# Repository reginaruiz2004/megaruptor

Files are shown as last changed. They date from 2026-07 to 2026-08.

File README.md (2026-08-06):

# Megaruptor

An open-source, low-cost DNA shearing device built on the [Poseidon syringe pump](https://github.com/machineagency/poseidon) platform — designed as an accessible alternative to commercial mechanical shearing instruments (e.g., Diagenode Megaruptor 3) for genomic library preparation workflows, particularly long-read sequencing (Oxford Nanopore).

> **Status:** 🚧 In progress

---

## Overview

Mechanical DNA shearing instruments are a common bottleneck in labs working with long-read sequencing platforms, both in cost and accessibility. This project adapts the open-source Poseidon syringe pump design to build a functional, hackable shearing device using off-the-shelf electronics, 3D-printed parts, and standard insulin syringes as the shearing element.

The goal is a device that is:
- **Low-cost** — built from widely available components
- **Reproducible** — fully documented, open hardware
- **Hackable** — easy to modify shear force/speed parameters for different fragment size targets

---

## How It Works

DNA is sheared by repeatedly forcing a sample through a narrow-gauge needle at controlled speed, using a syringe pump mechanism driven by a stepper motor. Shear force and fragment size distribution are governed by needle gauge, plunger speed, and number of passes.

---

## Bill of Materials (Key Components)

| Component | Spec / Notes |
|---|---|
| Shearing element | BD Ultra-Fine 0.3 mL, 31G insulin syringes |
| Stepper motor | NEMA 17 |
| Motor driver | A4988 |
| Controller | CNC Shield V3 + Arduino Uno R3 |
| Safety | Mechanical limit switch (NC, fail-safe primary) + current sensing (secondary) |
| Frame/structural parts | 3D-printed (PLA), based on Poseidon design |

Full BOM with vendor links: [`docs/BOM.md`](docs/BOM.md) *(coming soon)*

---

## 3D Printed Parts

This build uses 4 standard components from the original Poseidon design, plus 2 custom parts designed for this build:

| Part | Type | Notes |
|---|---|---|
| Poseidon base/frame components (×4) | Standard | From original Poseidon design |
| Sleeve adapter | Custom | OD 8 mm, ID 6.1 mm, 30 mm length |
| Eppendorf bracket | Custom | 45° angle mount |

All STL files are available in [`/STL`](./STL). Source CAD files (where available) are in [`/CAD`](./CAD).

---

## Repository Structure

```
megaruptor/
├── README.md
├── STL/                  # Printable 3D files
├── CAD/                  # Source CAD files (Fusion 360 / FreeCAD)
├── firmware/             # Arduino control code
├── docs/
│   ├── BOM.md            # Full bill of materials with vendors/costs
│   ├── DECISIONS.md      # Design decisions & rationale
│   ├── ASSEMBLY.md       # Build/assembly instructions
│   └── images/           # Build photos
```

---

## Design Decisions

Key engineering choices and their rationale are documented in [`docs/DECISIONS.md`](docs/DECISIONS.md), including:
- Hybrid safety design (mechanical limit switch + current sensing) over software-only stall detection
- Choice of insulin syringe gauge for shearing element
- Custom part tolerances (e.g., sleeve adapter fit)

---

## Build Progress

- [x] Source components (NEMA 17, A4988, Arduino Uno R3, syringes)
- [x] Design custom parts (sleeve adapter, Eppendorf bracket)
- [x] 3D print all components
- [x] Full mechanical assembly
- [ ] Firmware integration and motor control testing
- [ ] Validation with real DNA samples (fragment size distribution vs. commercial shearing)

---

## Progress Log

### July 21 2026
Mechanical assembly in progress. Key steps completed this round:

- Drilled out the rod holes on the 3D-printed PLA parts to fit the guide rods — the as-printed tolerances were too tight, so holes were carefully widened with a drill bit until the rods slid through smoothly.
- Installed screws on all designated screw holes across the printed parts to secure the frame.
- Threaded the brass (gold) lead screw nut onto the central leadscrew and secured it inside the carriage's nut trap with M3 screws, so it stays anti-rotated — this is what converts the leadscrew's rotation into linear motion, pulling the carriage along the two guide rods instead of just spinning freely with the screw.
- Mounted the carriage onto the guide rods and confirmed it slides smoothly along the full travel range by turning the leadscrew by hand.

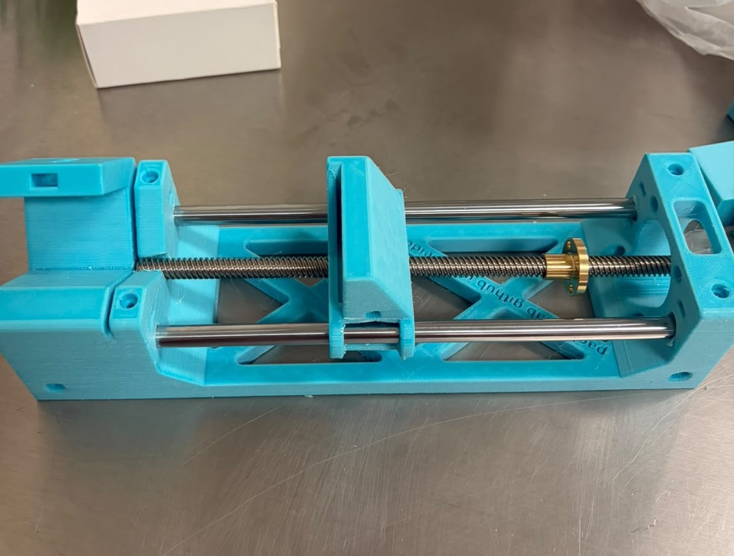
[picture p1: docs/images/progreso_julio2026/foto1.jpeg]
Progress Megaruptor


📹 [Watch the assembly video](docs/images/progreso_julio2026/video1.mp4)

### July 27, 2026

**A4988 Driver Calibration — Complete**

Key steps completed this round:

- Installed jumper headers at each motor position on the CNC shield to configure 1/2-step mode.
- Seated all four A4988 drivers into their respective positions on the CNC shield (X, Y, Z, and A axes).
- Mounted the CNC shield onto the Arduino UNO.
- Calibrated each A4988 driver to a reference voltage of 0.96V using a digital multimeter, with the negative probe on the CNC shield's GND pin and the positive probe used to measure the potentiometer during adjustment. This value was derived from: Vref = Imax × (8 × Rsense) = 1.2A × (8 × 0.1Ω) = 0.96V.
- Voltage adjustments were made by turning each driver's onboard potentiometer with a small screwdriver while simultaneously monitoring voltage with the multimeter's positive probe.
- Once all four drivers were calibrated to 0.96V, proceeded to connect the NEMA 17 stepper motor.
- **Note:** Many NEMA 17 motors ship with connectors where the wire color order differs between the motor and driver ends. This was the case here — the pin order did not match. To correct it, I released the terminals from the connector housing using a small screwdriver and reseated them in the correct sequence.
- Connected the NEMA 17 motor to the CNC shield via the X-axis A4988 driver.
- Stripped two jumper wires and connected them to the CNC shield's positive (+) and negative (–) power terminals to interface with the barrel jack adapter.

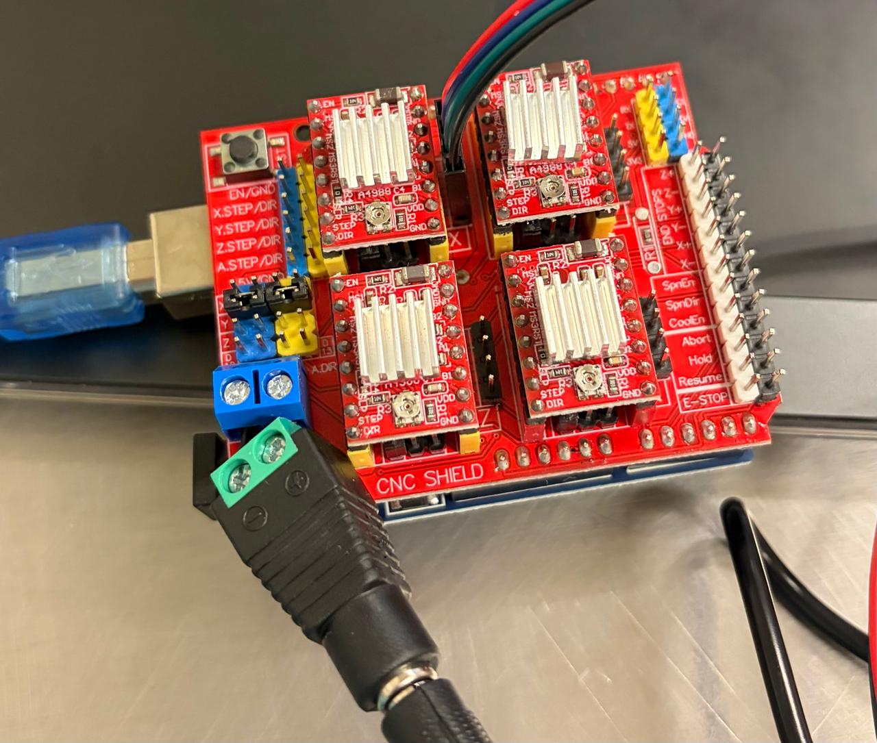
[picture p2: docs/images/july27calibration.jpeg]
Driver Calibration


### August 3, 2026

**NEMA 17 setup completed**

Key steps completed this round:

- Installed the NEMA17 into the megaruptor base support. Removed awkwardness when the NEMA17 motor turns on.
- Switched the main central screw to a smaller length one so it can all properly fit with now the NEMA17 closer to the whole device.
- I started having an issue with one of the rods whenever the cart moved forwards and backwards. The rod would also move with the cart's movements. To fix this, I setup longer screws in the base so that they would hold the rods in place without worry of any movement when the cart would begin to do its job.
- Completed a design of 3d printed case for the CNC shield and arduino. There are 5 openings in the case: Arduino USB cable, Jack Barrel power source for Arduino, On/Off switch, cart switch, and an opening for the NEMA 17 wires.

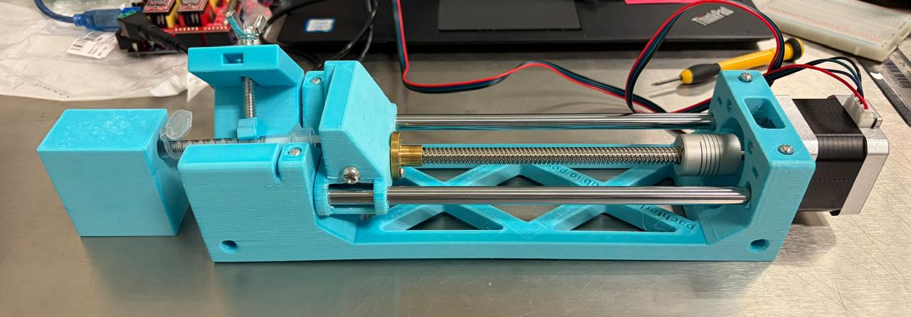
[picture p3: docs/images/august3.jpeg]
Setup


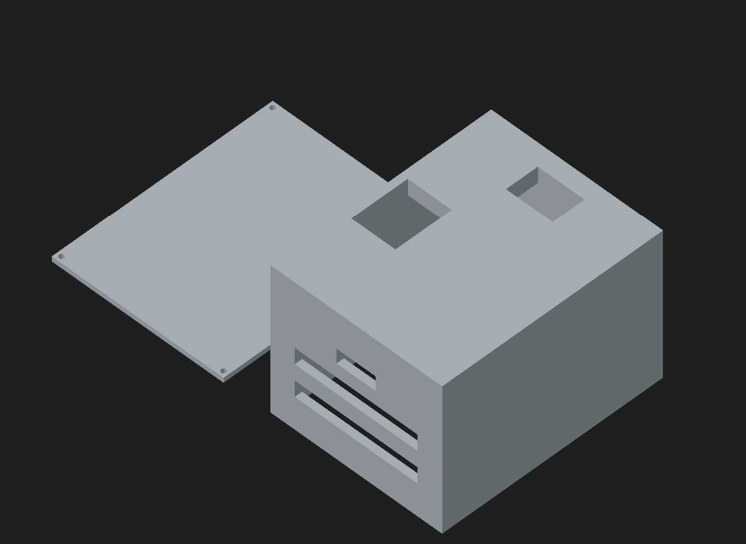
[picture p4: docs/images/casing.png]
Casing


### August 4, 2026

**3D Printed Case**

Key steps completed this round:

- I 3d printed the case for the electrical components.
- Switch assembly: On/Off switch, forwards/backwards switch that controls the cart movement

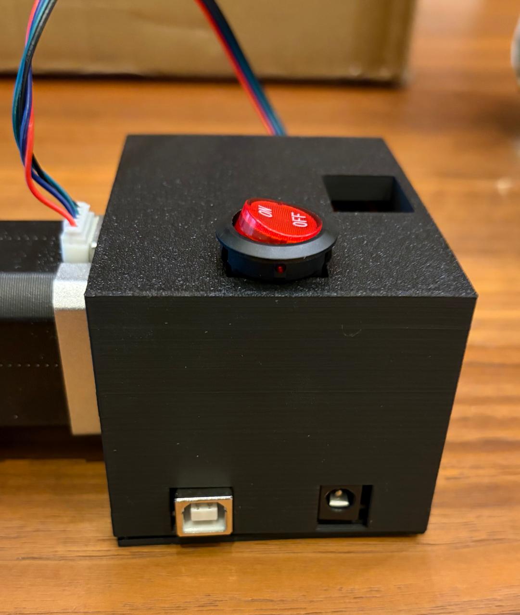
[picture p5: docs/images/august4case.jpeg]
Case

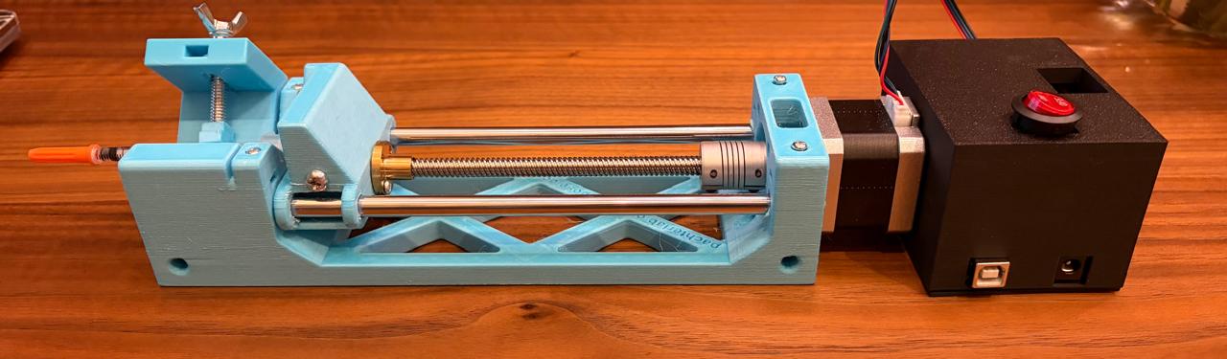
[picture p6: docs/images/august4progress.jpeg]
Complete machine


### August 5, 2026

**Complete setup of megaruptor**

Key steps completed this round:

- Connected the switch that moves the cart forwards and backwards. I connected it directly to the CNC shield instead of the Arduino. Why? Because all of the pins from the arduino are taken by the CNC shield since it is stacked. Therefore, there are pins in the CNC shield that are available to act as digital pins. (Y+ and Z- were used in this case)
- Connected the on and off switch with the following circuit. Terminal 1 (LED) was connected to the gnd of the CNC shield. There was also a wire from CNC shield GND soldered to the Arduino GND pin of the jack barrel connector. Then Terminal 2 (common) was connected to the + of the CNC shield. And then terminal 3 of the switch was soldered to the + pin of the jack barrel terminal. Therefore, when you connect the jack barrel connector to the arduino, voltage has to first go through the switch before reaching the CNC shield.
- After setting up all the necessary switches, it was time to set it up with the case. The switches went into their designated spots in the case and a zip tie was used to organize all loose wires. I plan to add magnets to the back of the NEMA17 and the case so the whole machine can be in one piece rather than two separate pieces.

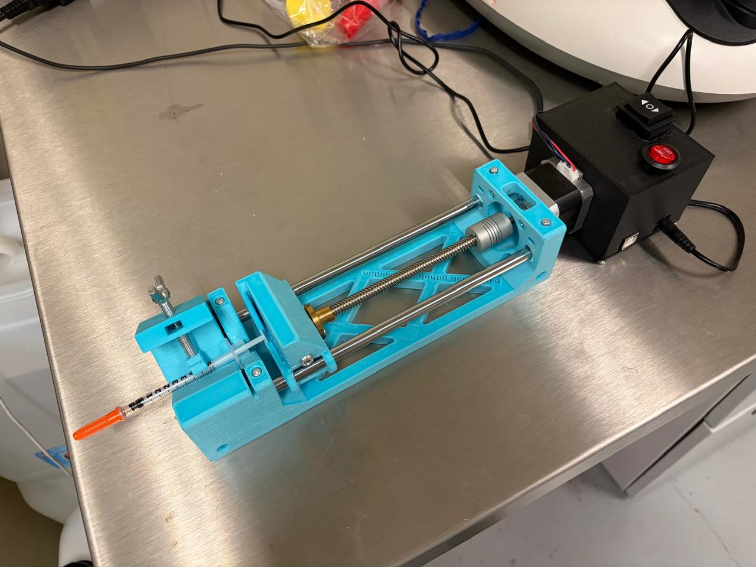
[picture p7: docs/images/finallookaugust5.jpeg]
Complete setup


---

## Acknowledgments

This project builds on the open-source [Poseidon](https://github.com/machineagency/poseidon) syringe pump platform. Full credit to the original design team for the foundational mechanical design this project adapts.

---

## License

*(To be determined — consider MIT for firmware/code and CC-BY or CC-BY-SA for hardware designs)*

---

## Author

**Regina Ruiz** — Bioinformatics / Lab Sciences, Granatum Bioworks
[GitHub](https://github.com/reginaruizb)

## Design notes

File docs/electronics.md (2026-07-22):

# Electronics Documentation

This section documents the electronics design for the Megaruptor, developed in KiCad. Two designs are included: a wiring diagram of the control electronics as currently assembled, and a proposed custom PCB shield that could replace the generic CNC Shield V3.

---

## 1. Wiring Diagram

A schematic capturing the full control circuit: Arduino Uno R3, A4988 stepper driver, NEMA 17 motor, power switch, limit switch (fail-safe), and 12V barrel jack input.

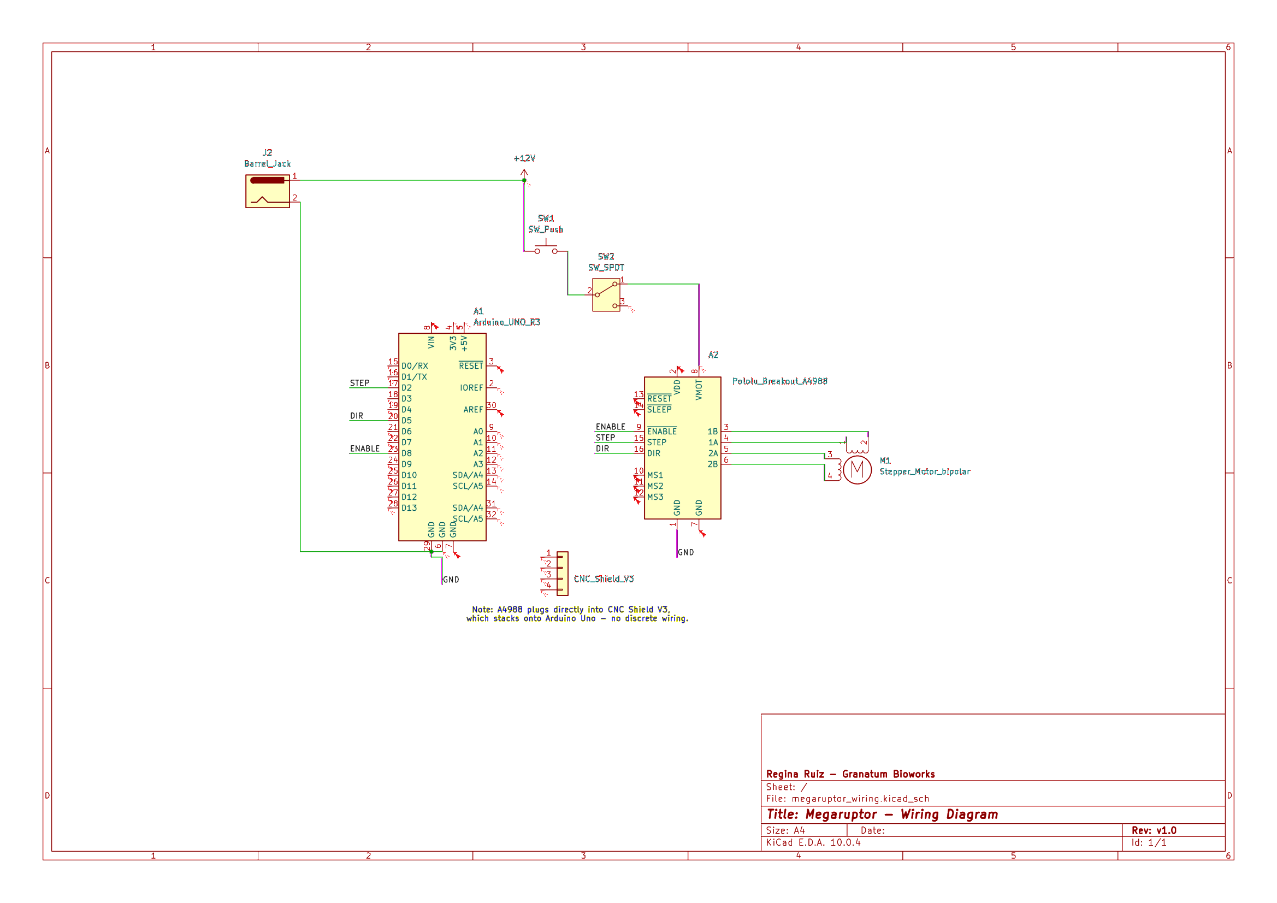
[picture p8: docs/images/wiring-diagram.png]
Wiring Diagram


### Key design points
- **Fail-safe power path:** +12V flows through the general power switch (SW1) and then through the limit switch (SW2, wired NC) before reaching the driver's VMOT pin. If the limit switch is triggered, motor power is cut directly — no firmware dependency. See [DECISIONS.md](DECISIONS.md#safety-system-hybrid-mechanical-limit-switch--current-sensing) for the rationale.
- **Control signals:** STEP (D2), DIR (D5), and ENABLE (D8) connect directly from the Arduino to the A4988. Physically, these pass through the CNC Shield V3 (noted on the diagram), which stacks onto the Arduino — no discrete wiring exists for this path.

KiCad project: [`electronics/megaruptor_wiring/`](../electronics/megaruptor_wiring/)

---

## 2. Custom Shield PCB (Proposed Design)

A proposed custom PCB shield that would replace the generic CNC Shield V3 — sized to the Arduino Uno standard shield footprint (53.4mm x 68.6mm), carrying only the signals actually used by this build (STEP, DIR, ENABLE, GND, +12V power path, and motor terminal).

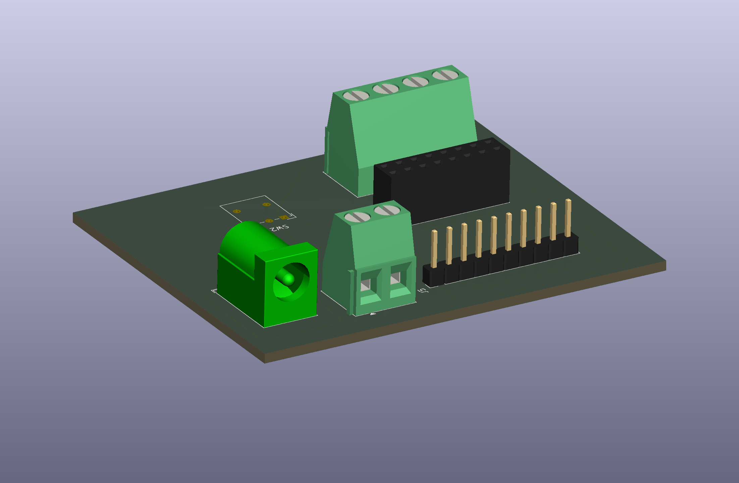
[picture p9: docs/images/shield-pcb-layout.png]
Shield PCB Layout


📄 [Download full PCB plot (PDF)](megaruptor_shield.pdf)

### Why a custom shield
The CNC Shield V3 is designed for 3-axis CNC control (X/Y/Z), but this build only drives a single stepper motor. A custom shield:
- Removes unused headers/drivers for the other two axes
- Integrates the fail-safe switch wiring directly onto the board instead of external jumper wires
- Is a natural next step if this design moves toward small-batch fabrication

### Component footprints used
| Component | Footprint |
|---|---|
| J2 (Barrel Jack) | `BarrelJack_Horizontal` (5.5mm x 2.1mm) |
| J5 (Arduino connection) | `PinHeader_1x10_P2.54mm_Vertical` |
| A2 (A4988 driver) | `PinSocket_2x08_P2.54mm_Vertical` (socketed, not soldered direct) |
| SW1 (power switch) | `TerminalBlock` 1x02 (external rocker switch, wired by cable) |
| SW2 (limit switch) | `SW_Lever_1P2T_NKK_GW12LxH` |
| M1 (motor) | `TerminalBlock` 1x04 |

**Status:** Schematic and PCB layout complete, 0 DRC errors. Not yet fabricated.

KiCad project: [`electronics/megaruptor_shield/`](../electronics/megaruptor_shield/)

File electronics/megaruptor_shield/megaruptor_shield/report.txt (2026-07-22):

Info: Processing symbol 'A2:Connector_PinSocket_2.54mm:PinSocket_2x08_P2.54mm_Vertical'.
Info: Processing symbol 'J2:Connector_BarrelJack:BarrelJack_Horizontal'.
Info: Processing symbol 'J5:Connector_PinHeader_2.54mm:PinHeader_1x10_P2.54mm_Vertical'.
Info: Processing symbol 'M1:TerminalBlock_Phoenix:TerminalBlock_Phoenix_MKDS-1,5-4-5.08_1x04_P5.08mm_Horizontal'.
Info: Processing symbol 'SW1:TerminalBlock_Phoenix:TerminalBlock_Phoenix_MKDS-1,5-2-5.08_1x02_P5.08mm_Horizontal'.
Info: Processing symbol 'SW2:Button_Switch_THT:SW_Lever_1P2T_NKK_GW12LxH'.
Warning: No net found for component J2 pad 3 (no pin 3 in symbol).
Warning: No net found for component J5 pad 2 (no pin 2 in symbol).
Warning: No net found for component J5 pad 4 (no pin 4 in symbol).
Warning: No net found for component J5 pad 3 (no pin 3 in symbol).
Warning: No net found for component J5 pad 1 (no pin 1 in symbol).
Error: J5 pad D5 not found in Connector_PinHeader_2.54mm:PinHeader_1x10_P2.54mm_Vertical.
Error: J5 pad D8 not found in Connector_PinHeader_2.54mm:PinHeader_1x10_P2.54mm_Vertical.
Error: J5 pad GND not found in Connector_PinHeader_2.54mm:PinHeader_1x10_P2.54mm_Vertical.
Error: J5 pad D2 not found in Connector_PinHeader_2.54mm:PinHeader_1x10_P2.54mm_Vertical.

Info: Total warnings: 5, errors: 4.

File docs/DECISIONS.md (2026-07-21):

# Design Decisions

This document records key engineering decisions made during the build, along with the rationale behind them. Intended both as a build log and as reference for anyone adapting this design.

---

## Shearing Element: BD Ultra-Fine 0.3 mL, 31G Insulin Syringes

**Decision:** Use standard BD Ultra-Fine insulin syringes (0.3 mL, 31G needle) as the DNA shearing element, rather than a specialized/custom needle.

**Rationale:** Widely available, inexpensive, sterile, and consistent in gauge — removing a major source of part-to-part variability. The narrow 31G bore provides the shear force needed to fragment DNA as it's forced through under controlled plunger speed.

**Status:** Confirmed, in use.

---

## Safety System: Hybrid (Mechanical Limit Switch + Current Sensing)

**Decision:** Use a **normally-closed (NC) mechanical limit switch** as the primary fail-safe, with **current sensing** as a secondary/backup layer, rather than relying on software-only stall detection.

**Rationale:**
- A software-only approach (e.g., detecting stepper stall purely from expected vs. actual position) is not fail-safe: if the controller hangs, crashes, or the logic has a bug, there's nothing physically stopping the motor.
- An NC limit switch fails safe by design — if the switch, its wiring, or its connector fails, the circuit opens and the motor stops, rather than failing silently in the "everything is fine" state.
- Current sensing adds a second, independent detection method (motor drawing excess current under mechanical resistance/jam), catching failure modes the limit switch alone wouldn't (e.g., an obstruction before the switch is reached).

**Status:** Design finalized. Implementation pending full assembly.

---

## Custom Part: Sleeve Adapter

**Decision:** Design a custom sleeve adapter (OD 8 mm, ID 6.1 mm, 30 mm length) rather than using a stock Poseidon part.

**Rationale:** The stock Poseidon design didn't have a part matching the interface needed between the syringe holder and the linear rod system in this build's configuration. Dimensions were chosen to match the 8 mm linear rod OD while providing a snug fit for the mating component.

**Status:** Designed. Pending print + fit validation.

**Open item:** Tolerances (0.85 / 0.90 mm clearance, TBD which surfaces) still need double-checking against the actual assembled hardware — flagged in [BOM.md](BOM.md#open-items).

---

## Custom Part: Eppendorf Bracket (45°)

**Decision:** Design a custom bracket to hold an Eppendorf tube at a 45° angle, rather than a vertical/horizontal mount.

**Rationale:** *(add specific reasoning here — e.g., angle relative to shearing mechanism, ergonomics of loading/unloading, or clearance constraints)*

**Manufacturing note:** This part has a diagonal internal channel at 45° and **requires print supports**. Without supports, the interior tunnel deforms during printing, which would compromise fit and function. Documented in [BOM.md](BOM.md#3d-printed-parts).

**Status:** Geometry finalized ("Angulos del eppendorf — DONE" per build notes). Pending print with correct support settings.

---

## Print Settings: PLA, 0.2 mm Layer Height, 3 Perimeters

**Decision:** Standardize all structural 3D-printed parts on PLA, 0.2 mm layer height, 3 perimeters/walls, 50 mm/s print speed.

**Rationale:** *(add specific reasoning here — e.g., balance of print time vs. structural strength needed for the pump body and moving parts under repeated mechanical load)*

**Status:** Confirmed standard for this build.

---

## Base Platform: Poseidon Syringe Pump

**Decision:** Build on the open-source Poseidon design rather than designing a shearing mechanism from scratch.

**Rationale:** Poseidon is an already-validated, open-source syringe pump platform, letting this project focus engineering effort on the DNA-shearing-specific adaptations (custom parts, safety system, shearing element choice) rather than re-solving general syringe pump mechanics.

**Status:** Confirmed. 4 standard Poseidon parts used as-is (`pump_body`, `pump_sled`, `syringe_holder`, `motor_mount`), 2 custom parts added (sleeve adapter, Eppendorf bracket).

---

## Template for Future Entries

```
## [Decision Title]

**Decision:** What was decided.

**Rationale:** Why — what alternatives were considered and why this won.

**Status:** Confirmed / In progress / Superseded by [link].
```

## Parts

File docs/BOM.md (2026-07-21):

# Bill of Materials

All prices in **MXN (Mexican pesos)**, sourced locally by the author. Links/vendors to be added as available.

## 3D Printed Parts

| Part | Description |
|---|---|
| `pump_body` | Main pump structure |
| `pump_sled` | Carriage that pushes the syringe plunger |
| `syringe_holder` | Holds the syringe barrel |
| `motor_mount` | NEMA 17 motor mount |

> Custom parts (sleeve adapter, Eppendorf bracket) are tracked separately — see [Design Decisions](DECISIONS.md).

### Print Settings

| Setting | Value |
|---|---|
| Material | PLA |
| Layer height | 0.2 mm |
| Perimeters / walls | 3 |
| Print speed | 50 mm/s (normal) |

**⚠️ Print note:** The Eppendorf bracket (in the `ExtraBases` file) has a diagonal 45° internal channel and **requires supports**. Without supports, the interior tunnel deforms during printing.

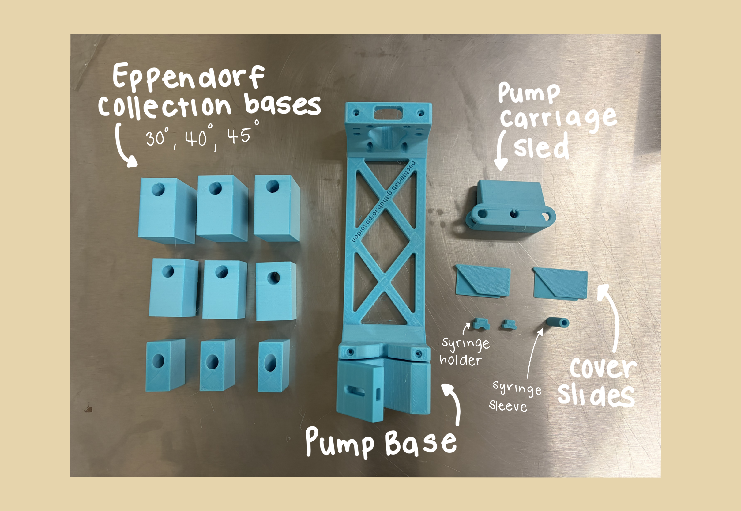
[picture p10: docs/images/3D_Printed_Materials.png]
3D Printed Parts


---

## Mechanical Components

| Component | Cost (MXN) |
|---|---|
| NEMA 17 motor (1.7 A, 200 steps) | 166.34 |
| T8 lead screw, 200 mm + bronze nut | 80.00 |
| Linear rods, 8 mm × 200 mm (×2) | 221.00 |
| LM8UU linear bearings | 80.00 |
| Coupler 5 mm–8 mm (motor to lead screw) | 190.00 |
| M3 screws (assorted) + nuts | 229.00 |
| Wing nuts / thumb screws | 664.00 |

## Electronics

| Component | Cost (MXN) |
|---|---|
| Arduino Uno | 131.24 |
| CNC Shield V3 | 159.00 |
| A4988 driver | *included with CNC Shield above* |
| 12V 2A power supply | 119.46 |
| Wiring / connectors | 115.00 |
| Switch | 167.00 |
| Auto shutoff system | — |
| Zip ties | 41.00 |

Electrical & Mechanical Components
---

## Total (approx.)

**~$1,738 MXN**

> Note: this is the author's working estimate. Some line items above may reflect bulk purchases or partial units — a fully itemized cost breakdown will be added as the BOM is finalized.

---

## Open Items

- [ ] Double-check dimensions/tolerances: **0.85 and 0.90** (device calibration — see build notes)
- [x] Eppendorf angle bracket geometry — done
- [ ] Add vendor links per component
- [ ] Reconcile itemized costs with total

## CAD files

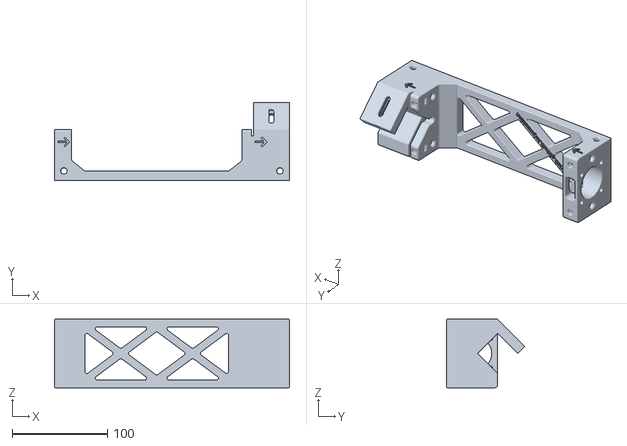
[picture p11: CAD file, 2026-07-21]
STL/Pump Base v51 (2).stl
247.0 x 82.3 x 72.0

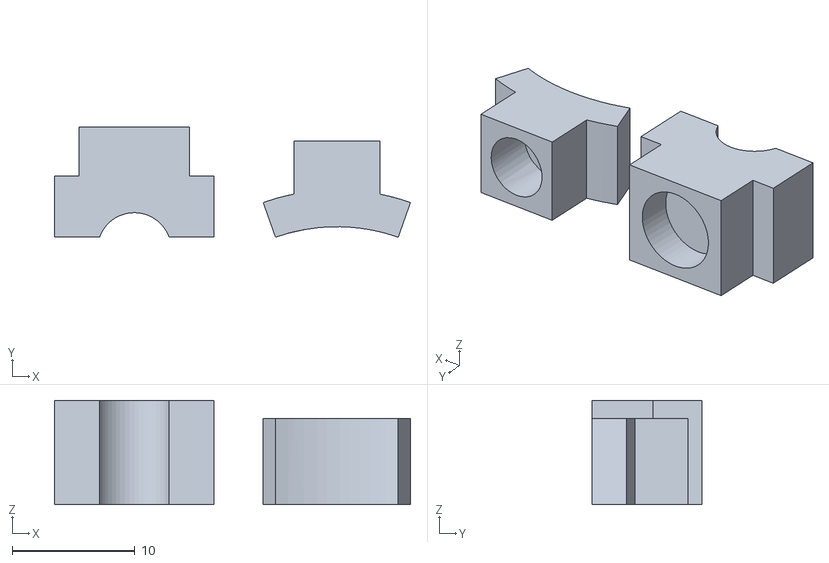
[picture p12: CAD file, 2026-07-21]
STL/Syringe Bases.stl
29.0 x 9.00 x 8.50

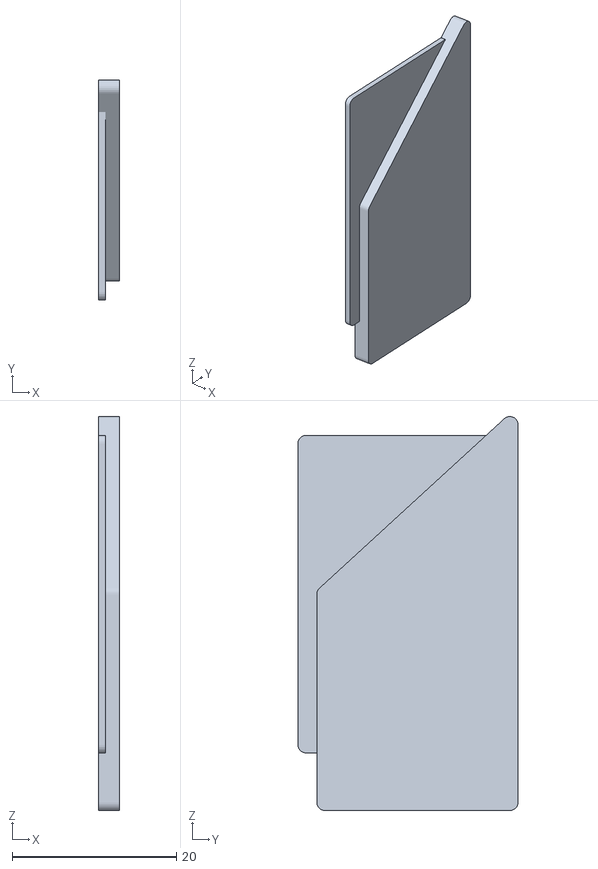
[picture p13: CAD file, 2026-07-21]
STL/Cover Slide Thin.stl
2.50 x 26.8 x 47.9

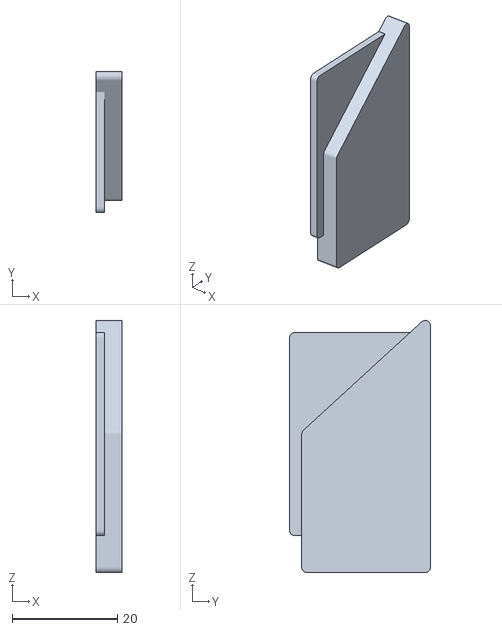
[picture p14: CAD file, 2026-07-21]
STL/Pump Cover Slide v51 (2).stl
5.00 x 26.8 x 47.9

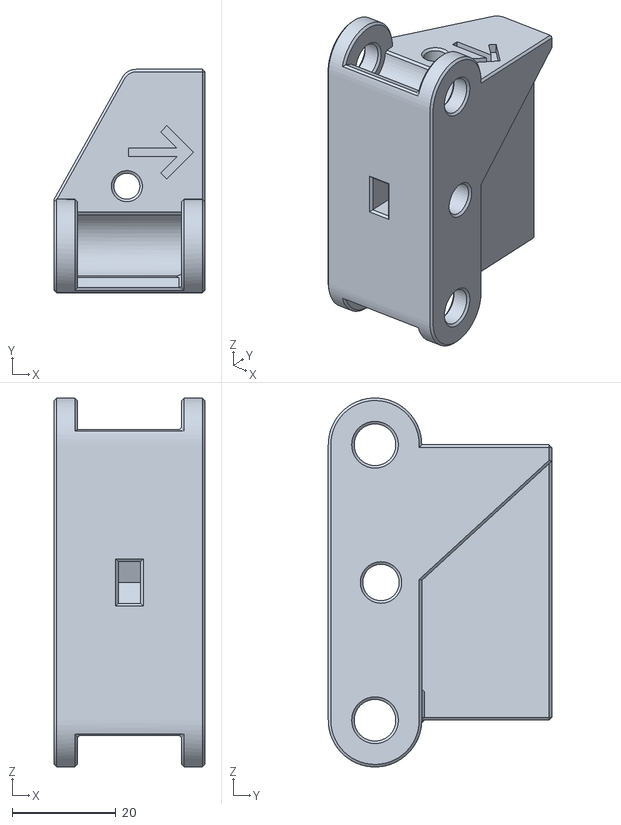
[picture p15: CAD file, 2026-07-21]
STL/Pump Carriage Sled v51 (2).stl
29.0 x 43.0 x 71.0

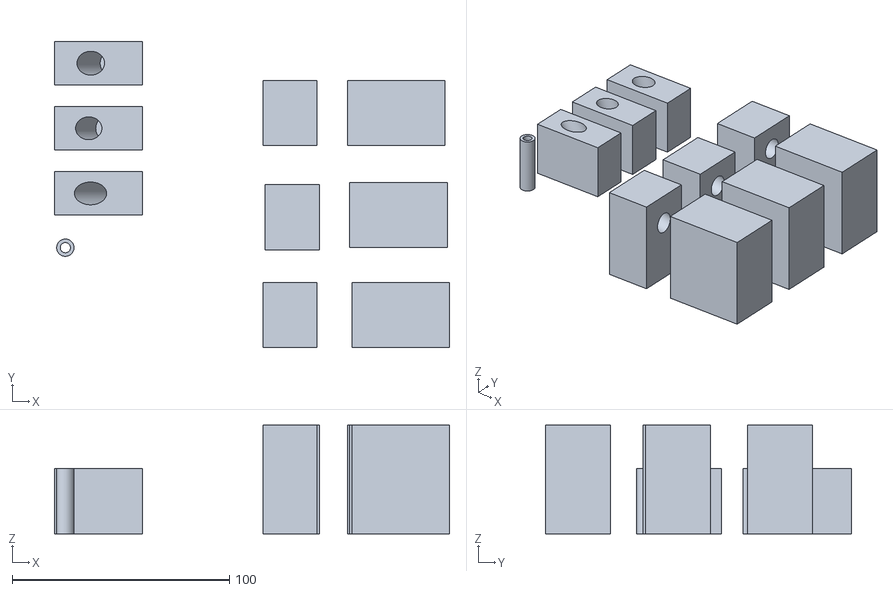
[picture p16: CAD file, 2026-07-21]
STL/Collection bases (1) (2).stl
182.0 x 141.0 x 50.0

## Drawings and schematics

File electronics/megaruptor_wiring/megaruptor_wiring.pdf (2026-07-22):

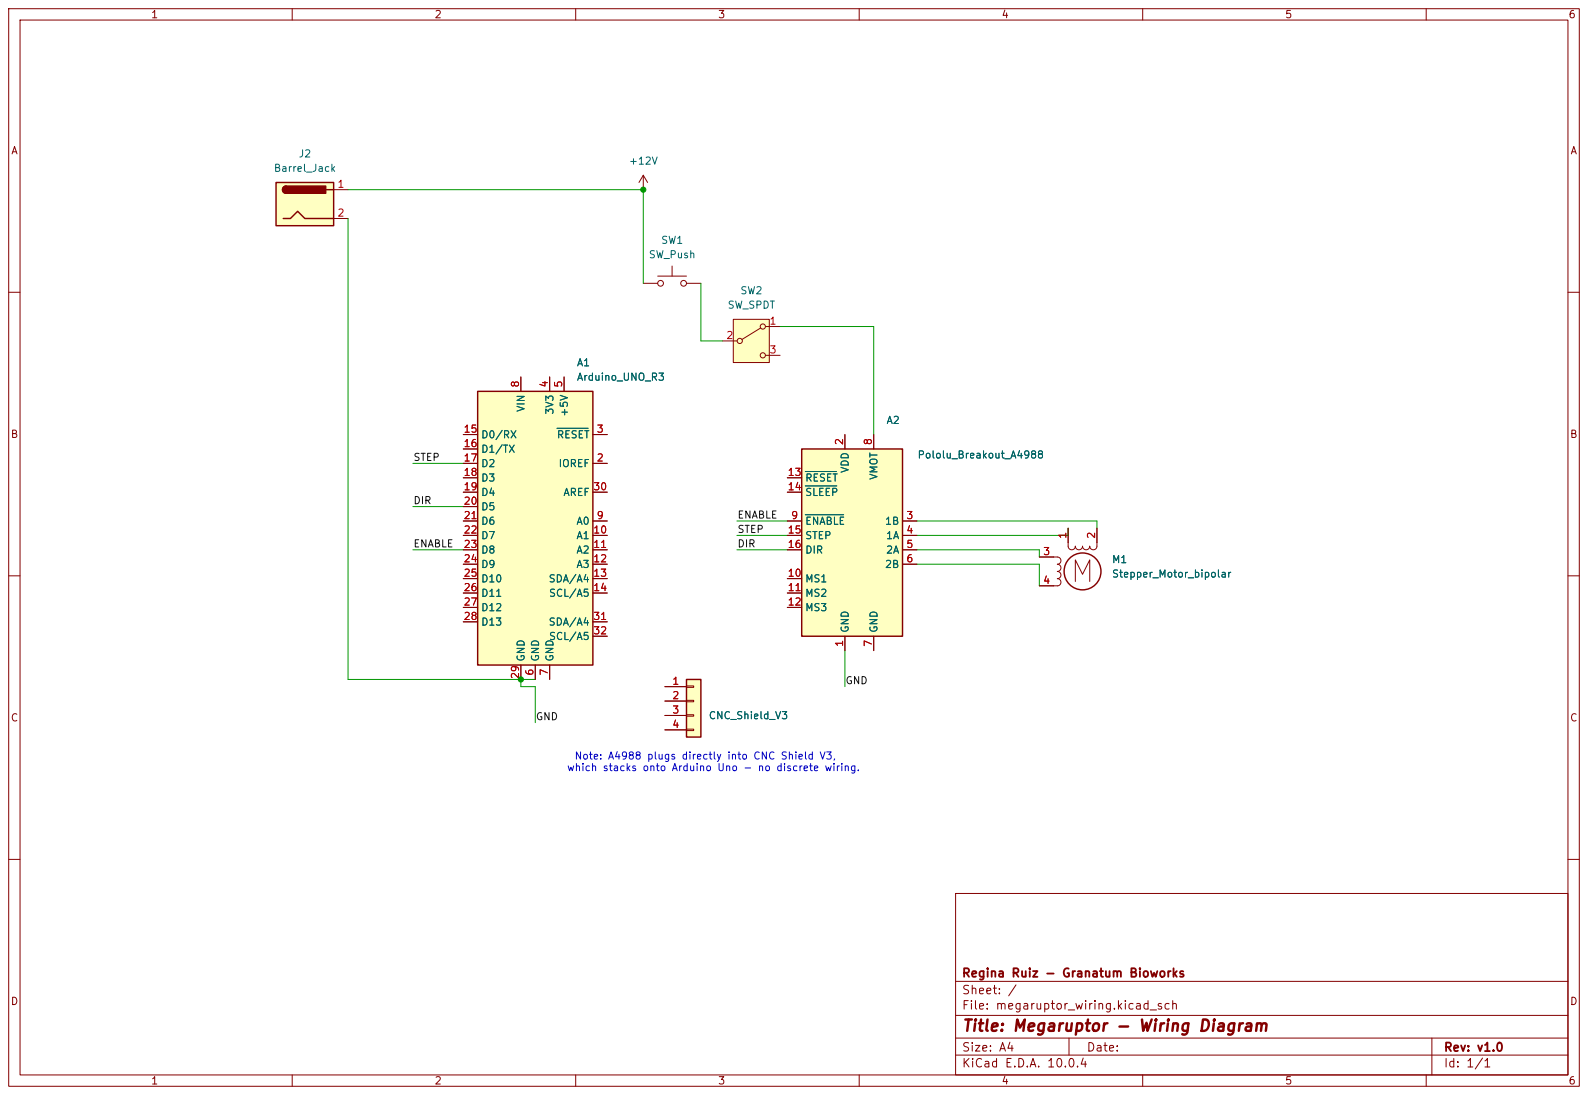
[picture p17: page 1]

Regina Ruiz - Granatum Bioworks
Sheet: /
File: megaruptor_wiring.kicad_sch
Title: Megaruptor - Wiring Diagram

Size: A4 | Rev: v1.0
KiCad E.D.A. 10.0.4 | Id: 1/1

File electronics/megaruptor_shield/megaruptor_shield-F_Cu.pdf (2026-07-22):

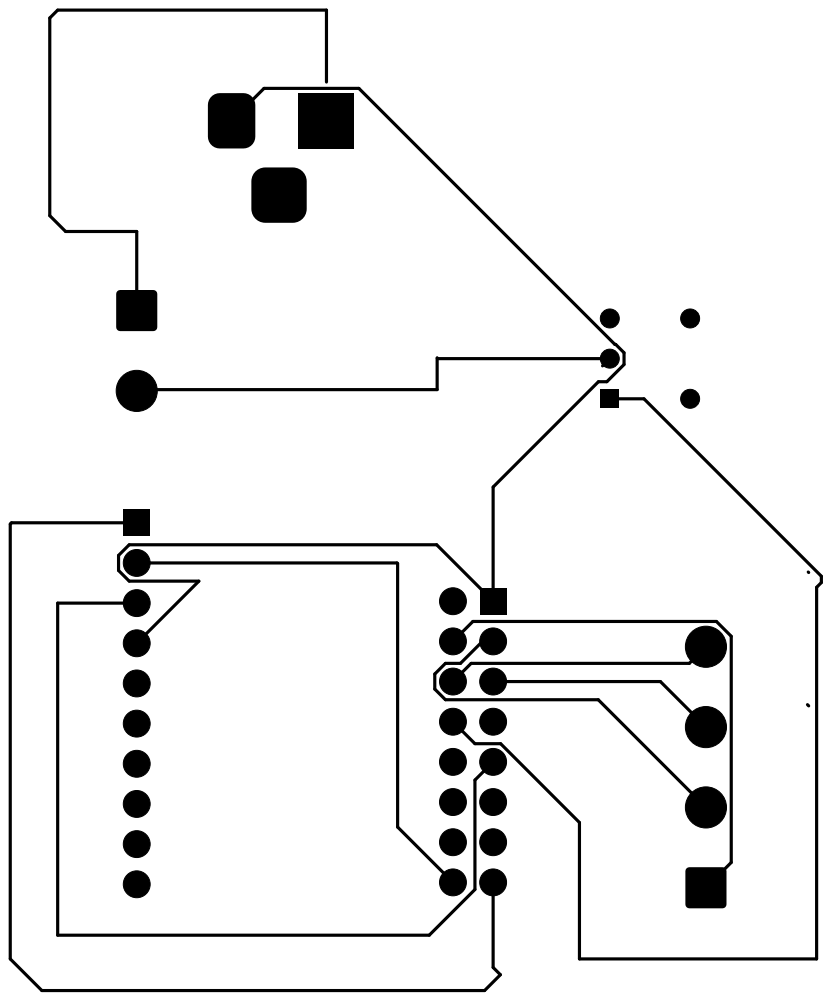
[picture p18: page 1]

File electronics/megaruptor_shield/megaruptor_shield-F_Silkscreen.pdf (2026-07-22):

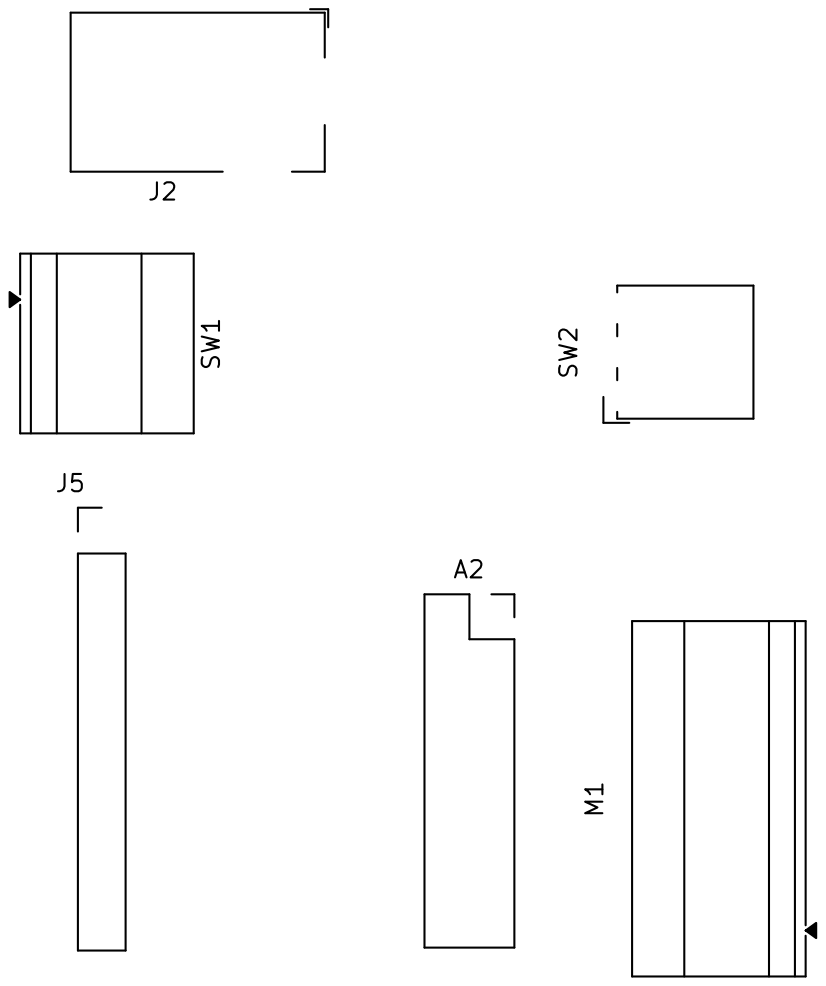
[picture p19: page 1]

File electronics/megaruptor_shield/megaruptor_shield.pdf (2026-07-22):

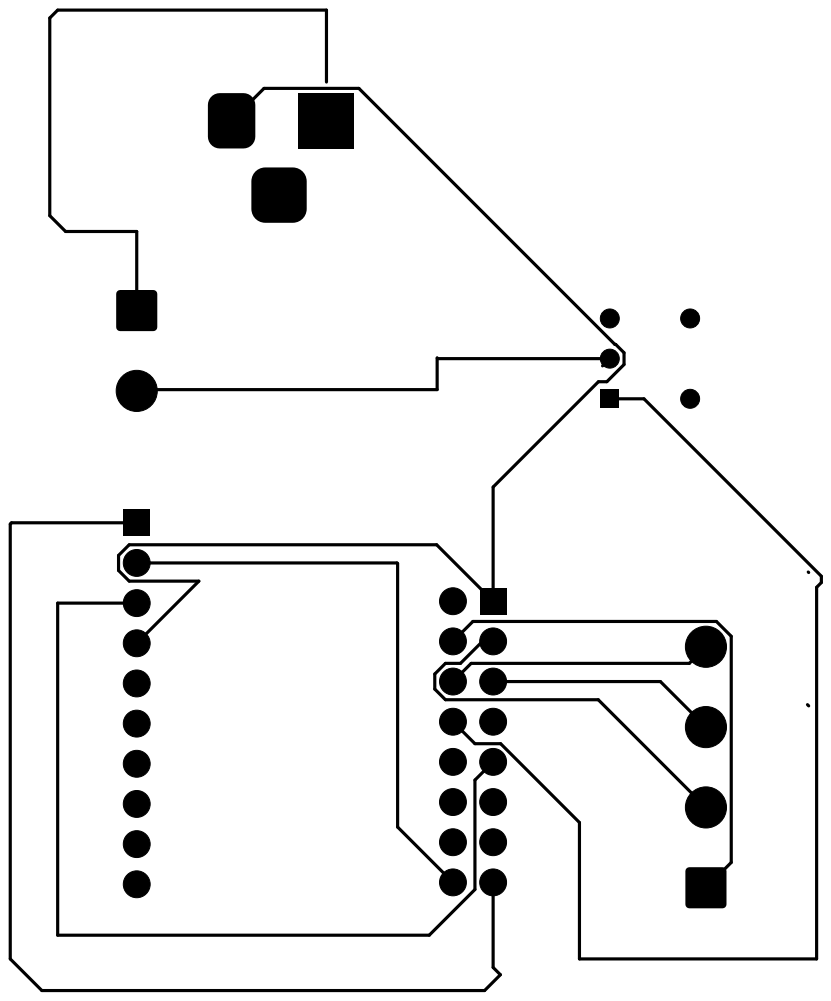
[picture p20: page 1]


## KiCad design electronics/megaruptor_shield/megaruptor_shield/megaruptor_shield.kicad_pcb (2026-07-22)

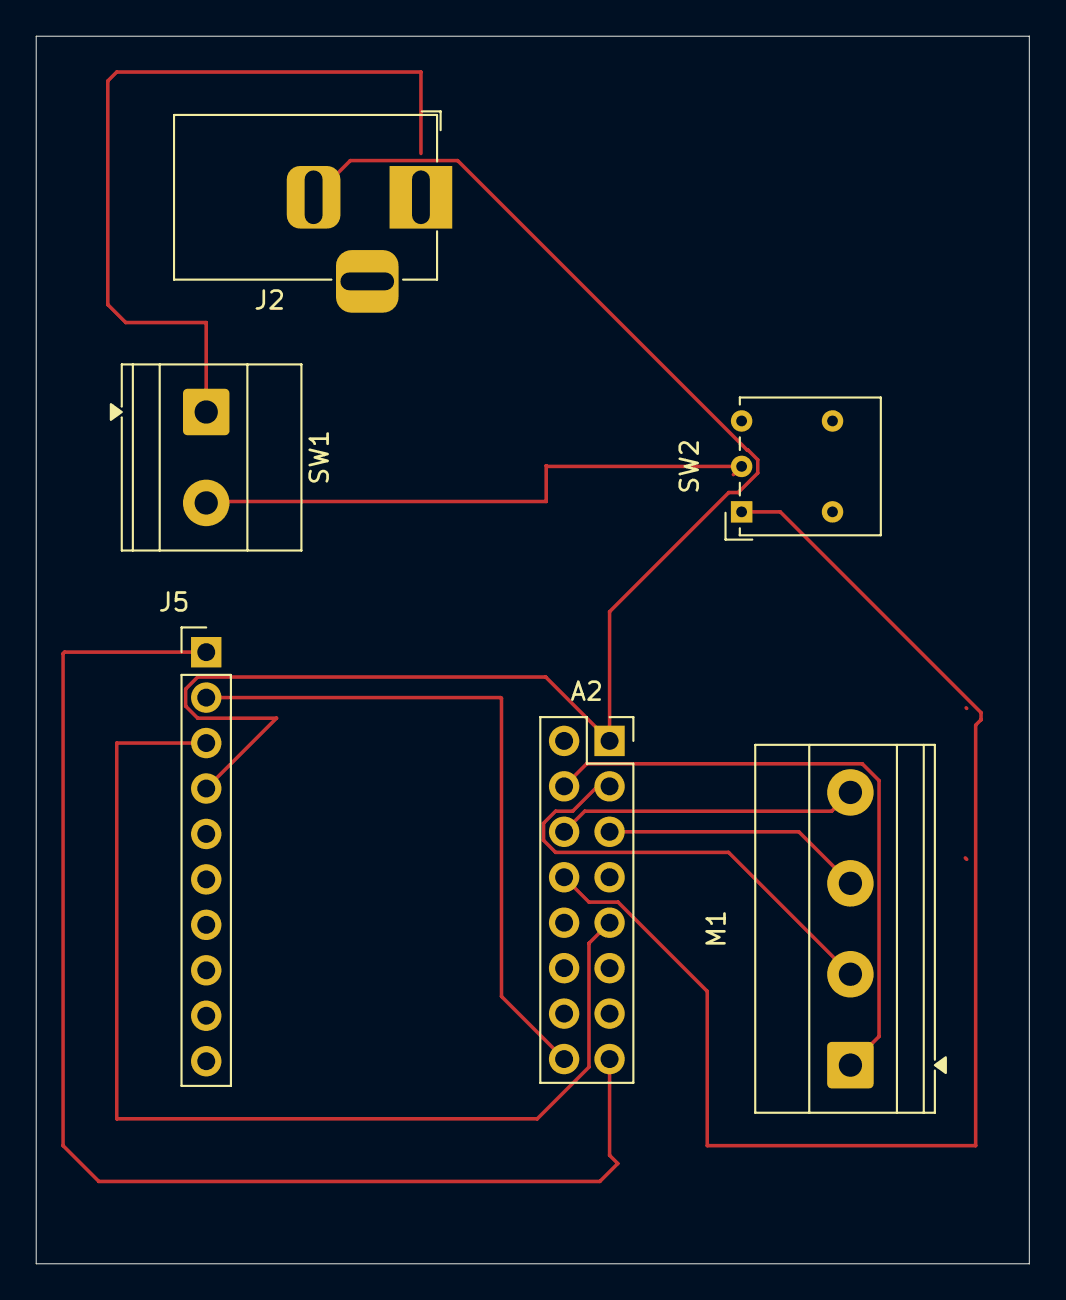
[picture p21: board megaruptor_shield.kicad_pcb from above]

Board: 2 copper layers, 55.5 x 68.6 mm, 6 parts (0 on the bottom side), 11 nets.

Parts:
A2: Pololu_Breakout_A4988; PinSocket_2x08_P2.54mm_Vertical
J2: Barrel_Jack; BarrelJack_Horizontal
J5: Conn_01x10; PinHeader_1x10_P2.54mm_Vertical
M1: Stepper_Motor_bipolar; TerminalBlock_Phoenix_MKDS-1,5-4-5.08_1x04_P5.08mm_Horizont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
SW1: SW_Push; TerminalBlock_Phoenix_MKDS-1,5-2-5.08_1x02_P5.08mm_Horizont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
SW2: SW_SPDT; SW_Lever_1P2T_NKK_GW12LxH

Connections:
+12V: J2.1, SW1.1
/DIR: A2.16 (DIR), J5.2 (D5)
/ENABLE: A2.9 (~ENABLE), J5.3 (D8)
/GND: A2.1 (GND), J2.2, J5.4 (GND)
/STEP: A2.15 (STEP), J5.1 (D2)
unnamed: A2.4 (1A), M1.1
unnamed: A2.3 (1B), M1.2 (-_2)
unnamed: A2.5 (2A), M1.3
unnamed: A2.6 (2B), M1.4
unnamed: A2.8 (VMOT), SW2.1 (A)
unnamed: SW1.2, SW2.2 (B)

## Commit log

2026-07-22 Add electronics documentation with wiring diagram and shield PCB design
    [megaruptor_shield-B_Cu.gbr, megaruptor_shield-B_Mask.gbr, megaruptor_shield-B_Paste.gbr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]
2026-07-24 Add Progress Log section with July 2026 assembly update
2026-07-28 Update A4988 calibration progress notes
